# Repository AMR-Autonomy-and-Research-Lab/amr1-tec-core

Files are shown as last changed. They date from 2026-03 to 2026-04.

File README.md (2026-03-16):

<div align="center">

<br/>



<br/><br/>

# AMR1-TEC-CORE

### Plataforma de Robótica Móvil Autónoma — Hardware + Firmware + CAD

<br/>







<br/>

> Plataforma completa de robótica móvil autónoma — incluye diseño CAD del chasis, PCB personalizada con bus CAN, control de actuadores en lazo cerrado y telemetría en tiempo real. Desarrollada con estándares de producción para investigación en el Tec de Monterrey.

<br/>

</div>

---

## Visor 3D del Robot AMR1

<div align="center">

<br/>

**Chasis completo del AMR1 — haz clic para inspeccionar el ensamble 3D en tu navegador.**

<br/>

<a href="https://htmlpreview.github.io/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">
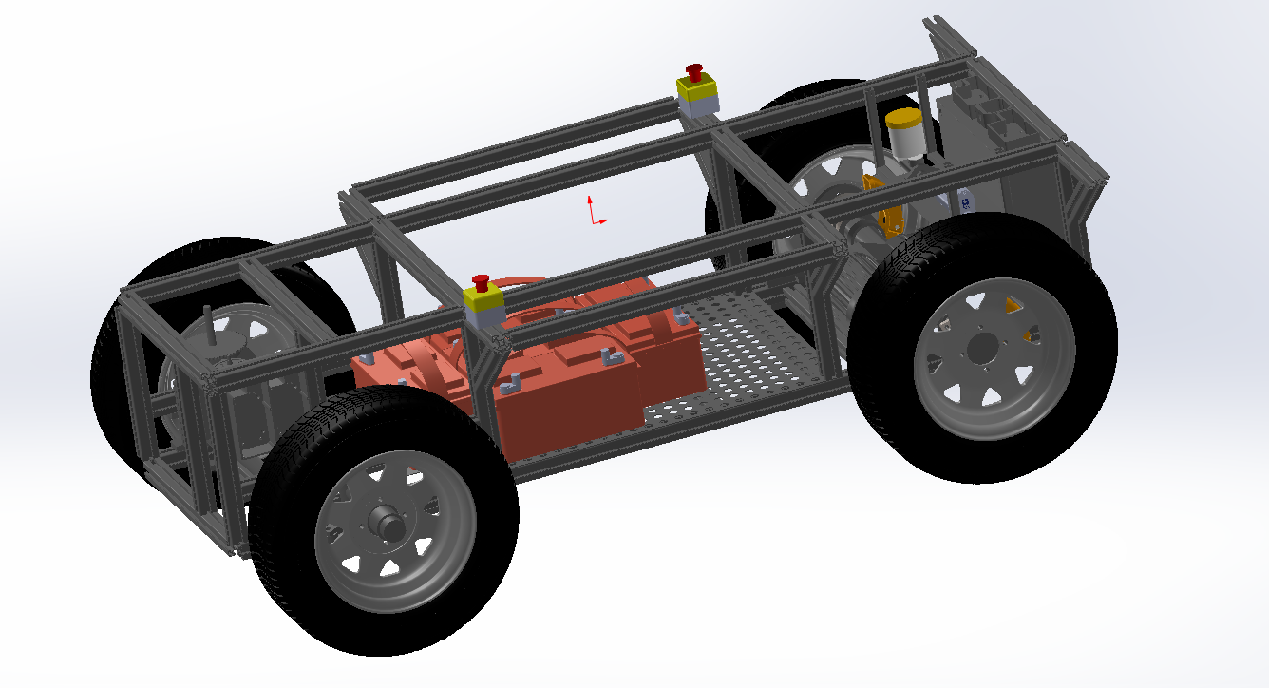
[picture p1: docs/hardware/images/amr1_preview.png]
Abrir Visor 3D del Robot AMR1
  
</a>

<br/><br/>

<a href="https://htmlpreview.github.io/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">
  
</a>

<br/><br/>

</div>

---

## Visor 3D de la PCB + Mapa iBOM

<div align="center">

<br/>

**PCB personalizada AMR1-TEC-CORE — haz clic para abrirla en el visor 3D interactivo.**

<br/>

<a href="https://htmlpreview.github.io/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">
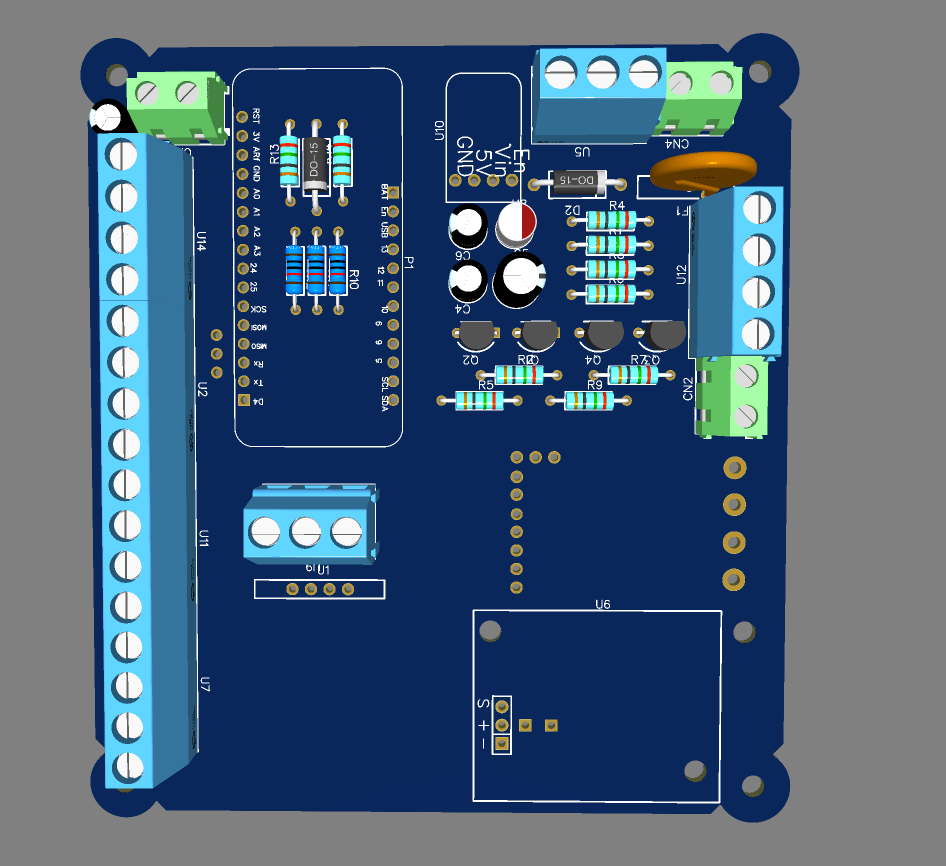
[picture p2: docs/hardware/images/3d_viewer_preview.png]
Abrir Visor 3D Interactivo de la PCB
  
</a>

<br/><br/>

<a href="https://htmlpreview.github.io/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">
  
</a>
&nbsp;&nbsp;
<a href="https://htmlpreview.github.io/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">
  
</a>

<br/><br/>

| Herramienta | Tecnología | Descripción |
|:---:|:---:|:---|
| **Visor 3D Robot** | WebGL · Three.js | Inspección del chasis completo en 3D |
| **Visor 3D PCB** | WebGL · Three.js | Inspección visual y verificación geométrica |
| **Mapa iBOM** | HTML interactivo | Guía de soldadura, localización de componentes |

<br/>

</div>

---

## Especificaciones Técnicas

<div align="center">

### Robot AMR1 — Sistema Completo

| Parámetro | Valor |
|---|---|
| Chasis | Diseño propio en SolidWorks |
| Tracción | 4 ruedas — Motor eléctrico MY1016Z3 |
| Frenado | Sistema hidráulico de pinza (Pololu Glideforce LD) |
| Alimentación | Batería 12 V |
| Control | Feather RP2040 CAN via Bus CAN |
| Comunicación | CAN 500 kbps |

### PCB — Control Central y Comunicaciones

| Parámetro | Valor |
|---|---|
| Microcontrolador | Adafruit Feather RP2040 CAN |
| Controlador CAN | MCP2515 (SPI) |
| Velocidad Bus CAN | 500 kbps |
| Entrada Serie | UART 115200 baud |
| Factor de Forma | Compatible Feather |

### PCB — Control de Actuador Lineal (Lazo Cerrado)

| Parámetro | Valor |
|---|---|
| Actuador | Pololu Glideforce High-Speed LD |
| Carga nominal | 12 kgf |
| Carrera | 6 pulgadas |
| Alimentación | 12 V |
| Control | PWM + Dirección + retroalimentación FLT |
| Sensor de posición | Potenciómetro (ADC) |

### PCB — Display de Telemetría a Bordo

| Parámetro | Valor |
|---|---|
| Display | SSD1306 OLED 128×64 |
| Interfaz | I²C |
| Datos mostrados | Estado CAN · Ciclo PWM · Corriente · Diagnóstico FLT |

</div>

---

## Arquitectura del Sistema

```
┌─────────────────────────────────────────────────────────┐
│                     AMR1 — Sistema Completo              │
│                                                          │
│  PC / ROS   ──UART 115200──►  Feather RP2040 CAN (TX)   │
│                                      │                   │
│                               Bus CAN 500 kbps           │
│                                      │                   │
│                         ┌────────────▼──────────────┐    │
│                         │  Feather RP2040 CAN (RX)  │    │
│                         │  + SSD1306 OLED 128×64    │    │
│                         └────────────┬──────────────┘    │
│                                      │                   │
│              ┌───────────────────────┼──────────────┐    │
│              │                       │              │    │
│         PWM+DIR                  PWM+DIR        I²C │    │
│              │                       │              │    │
│      ┌───────▼──────┐       ┌────────▼──────┐  ┌───▼──┐ │
│      │  Motor Drive  │       │ Actuador Lin. │  │ OLED │ │
│      │  MY1016Z3     │       │ Pololu 12kgf  │  │ 128x │ │
│      │  Tracción     │       │ ◄── ADC pos.  │  │  64  │ │
│      └───────────────┘       └───────────────┘  └──────┘ │
└─────────────────────────────────────────────────────────┘
```

---

## Estructura del Repositorio

```
amr1-tec-core/
├── AMR1_CAD/                    # Diseño CAD completo del robot
│   ├── amr1.SLDASM              # Ensamble principal SolidWorks
│   ├── amr1.STEP                # Export universal STEP
│   ├── amr1.glb                 # Modelo 3D optimizado para visor WebGL
│   └── *.SLDPRT                 # Piezas individuales del chasis
├── PCB_Design/
│   ├── PCB_AMR_Gerber/          # Gerbers validados — listos para fabricación
│   └── PCB_AMR_Gerber.zip       # ZIP directo para JLCPCB o PCBWay
├── 3D_Models/
│   └── PCB_3D/
│       └── PCB_Final.glb        # Modelo 3D de la PCB para el visor WebGL
├── feather_can_tx/              # Firmware: Transmisor Serial → CAN
├── feather_can_rx/              # Firmware: Receptor CAN + control de actuadores
├── Diseño_CAJA/                 # Modelos STL de la carcasa protectora
└── docs/hardware/
    ├── ibom_final.html          # Mapa interactivo de componentes (iBOM)
    ├── 3d_viewer/
    │   └── index.html           # Visor WebGL 3D de la PCB (auto-contenido)
    └── amr1_viewer/
        └── index.html           # Visor WebGL 3D del Robot AMR1 (auto-contenido)
```

---

## Fabricación de la PCB

Los archivos Gerber están validados y listos para ordenar directamente.

1. Ve a `PCB_Design/PCB_AMR_Gerber/` o descarga `PCB_AMR_Gerber.zip`
2. Sube el ZIP a [JLCPCB](https://jlcpcb.com) o [PCBWay](https://www.pcbway.com)
3. El diseño usa tolerancias comerciales estándar, taladros PTH/NPTH y máscara de soldadura doble capa — sin parámetros especiales

---

<div align="center">
<br/>

Desarrollado por el **AMR Autonomy and Research Lab** · Tecnológico de Monterrey



<br/>
</div>

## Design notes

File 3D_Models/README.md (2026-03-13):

# 🎨 Modelos 3D — AMR TEC Core

Modelos STL para impresión 3D y ensamblaje del robot AMR.

## Contenido

| Ubicación | Archivo | Descripción |
|---|---|---|
| `Diseño_CAJA/` | `CajaNuevaAMRF2.STL` | Enclosure/carcasa principal del sistema (v2, casi final) |

Este directorio está reservado para modelos 3D adicionales del proyecto.

## Especificaciones de impresión recomendadas

- **Material:** PLA o PETG
- **Espesor de capa:** 0.2 mm
- **Relleno:** 20–30%
- **Soporte:** Según geometría

## Visualización

Los archivos `.STL` pueden visualizarse con:
- [ViewSTL](https://www.viewstl.com/) (online)
- Blender
- Fusion 360
- PrusaSlicer / Cura

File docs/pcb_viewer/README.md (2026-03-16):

# PCB 3D Viewer (tscircuit)

Intento de integración con [@tscircuit/3d-viewer](https://github.com/tscircuit/3d-viewer).  
**Estado:** No compila por dependencias faltantes en el ecosistema tscircuit (miniflex, schematic-trace-solver, etc.).

## Alternativa

Usa **[pcb_viewer.html](../pcb_viewer.html)** para enlaces al playground de tscircuit y recursos PCB.

## Cómo probar tscircuit en el futuro

Si tscircuit corrige sus dependencias:

```bash
npm install
npm run dev
```

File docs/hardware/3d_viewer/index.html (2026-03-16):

## AMR1-TEC-CORE — Visor 3D de PCB

Clic + arrastrar: rotar · Rueda: zoom · Clic derecho: desplazar

Iniciando Three.js...

Error desconocido.

Abre la consola del navegador (F12 → Console) para ver el error completo.
↻ Reintentar

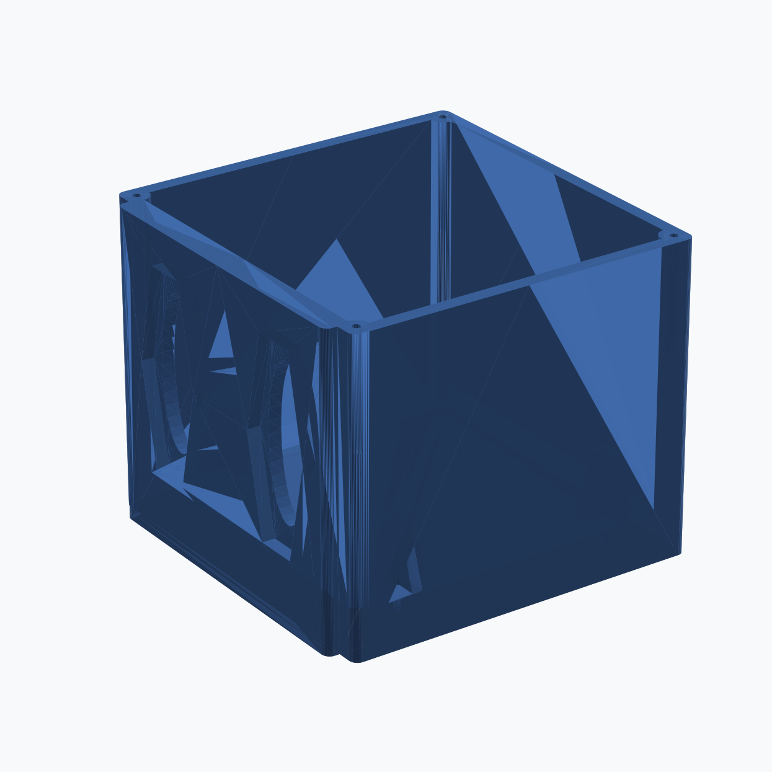
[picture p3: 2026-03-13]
docs/caja_preview.png

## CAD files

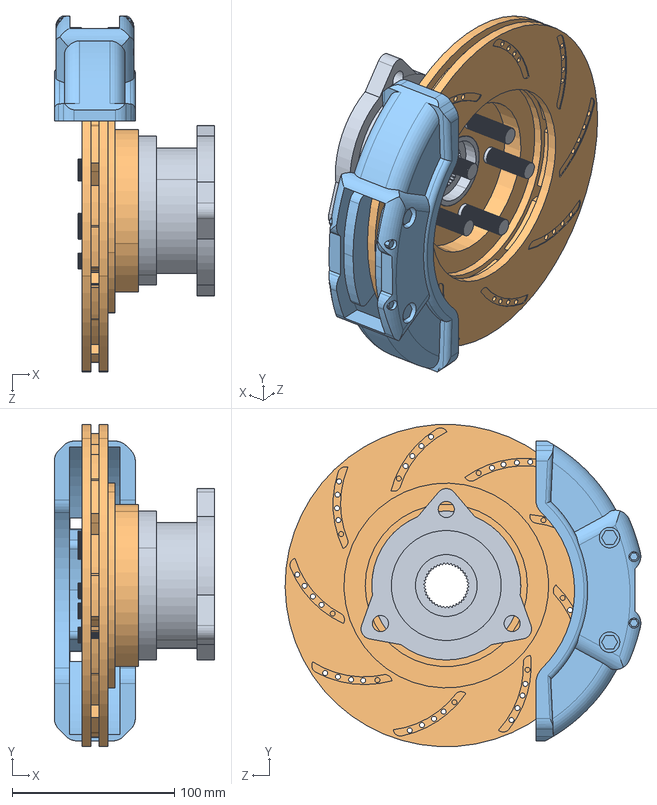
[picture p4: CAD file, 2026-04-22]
AMR1_CAD/assembly 2.SLDASM
98.9 x 198.5 x 219.3 mm
Hub 1
disc 1
calliper 1

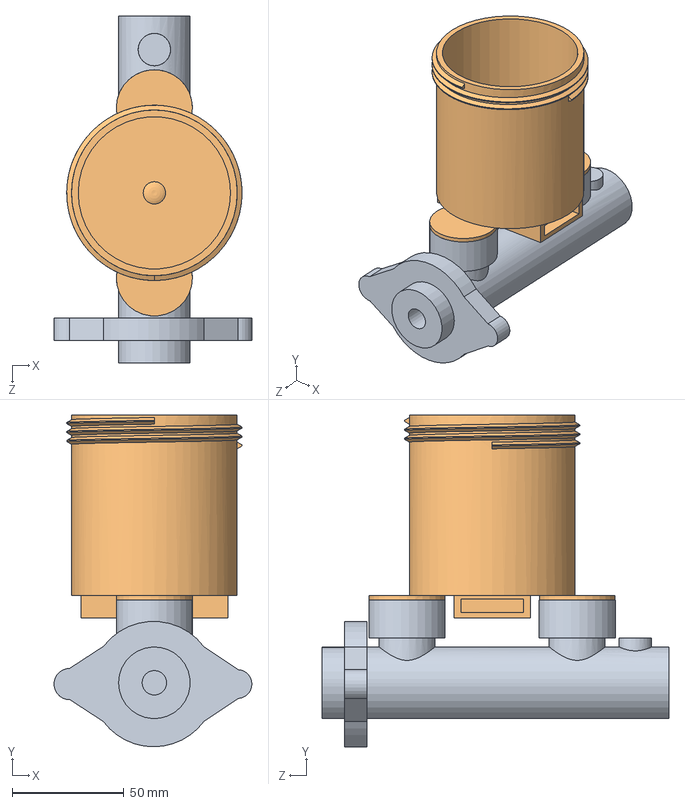
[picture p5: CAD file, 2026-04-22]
AMR1_CAD/Brake Fluid container with cylinder.SLDASM
88.4 x 148.1 x 155.0 mm
Zylinder vom Behälter
Bremsflüssigkeitsbehälter

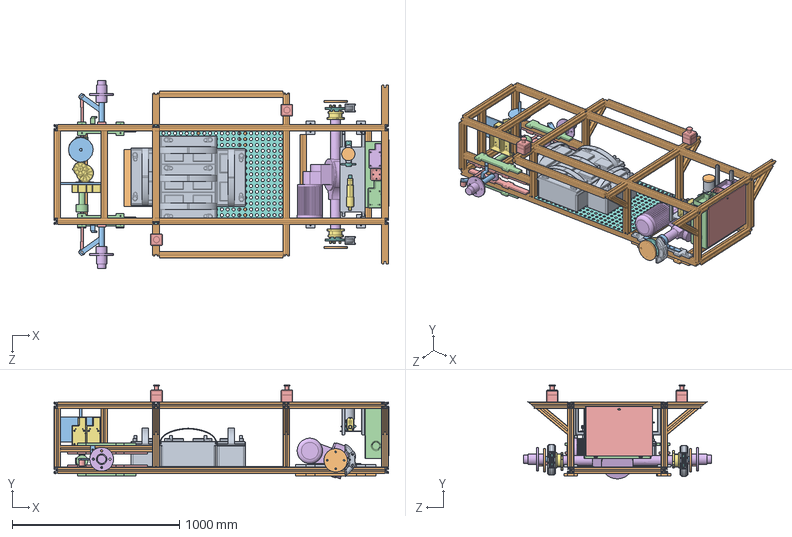
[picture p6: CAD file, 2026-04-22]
AMR1_CAD/amr1.SLDASM
2003.8 x 560.6 x 1122.0 mm
Rahmen Auto
control-module-plate
wheel-mounting1 x 4
wheel-mounting2 x 4
axle-joint x 2
cylinder-plate
Motor MY1016Z3
battery-plate
Battery x 5
battery-plate2
axle-front x 2
Blechkasten
Tür
wheel-connection x 2
aluminum-frame_2in with pot.step
extension-tube_2in frame.step
wheel-mounting1-back x 2
wheel-mounting2-back x 2
wheel-mounting3-back x 2
steering
steering-rod x 2
Powertrain
Hub 1 x 2
disc 1 x 2
calliper 1 x 2
distance-washer x 2
pinion
CarcasaInterprete
RelesFrenos
CarcasaFreno
CarcasaTrenMotriz x 2
Zylinder vom Behälter
Bremsflüssigkeitsbehälter
Behälter Deckel
steering-sensor-l
steering-sensor-r
emergency-buton x 2

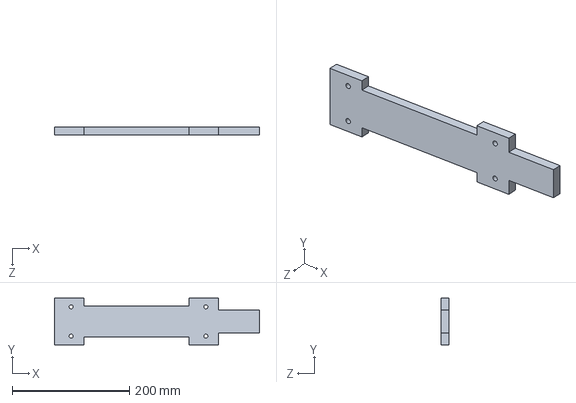
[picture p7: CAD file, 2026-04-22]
AMR1_CAD/wheel-mounting1.SLDPRT
350.0 x 80.0 x 13.0 mm

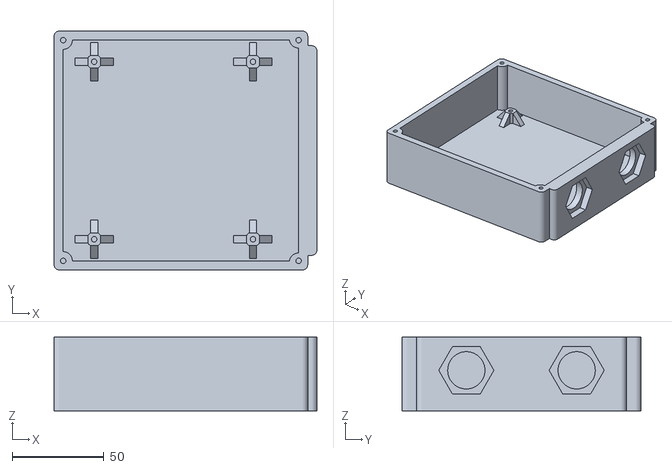
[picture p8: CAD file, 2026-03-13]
Diseño_CAJA/CajaNuevaAMRF2.STL
143.0 x 130.0 x 40.0

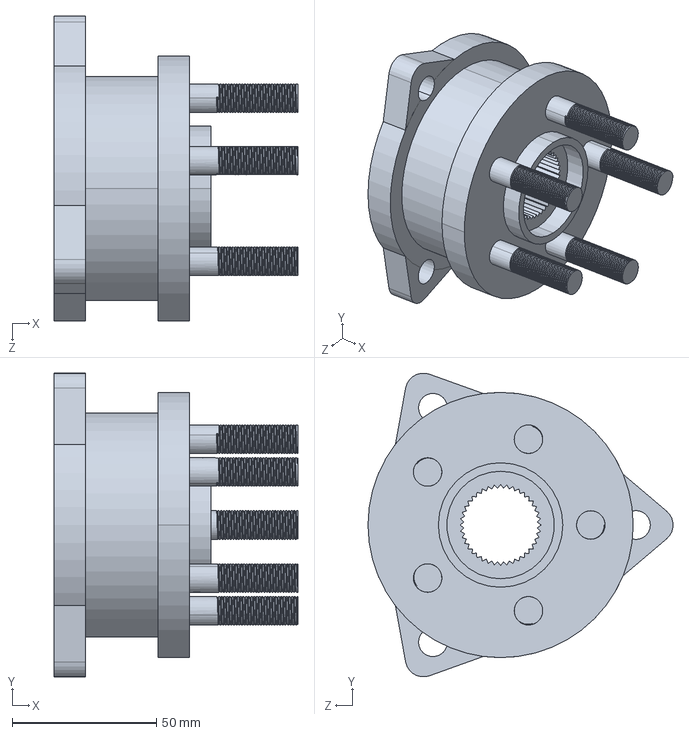
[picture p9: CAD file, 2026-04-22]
AMR1_CAD/Hub 1.SLDPRT
84.4 x 105.1 x 105.7 mm

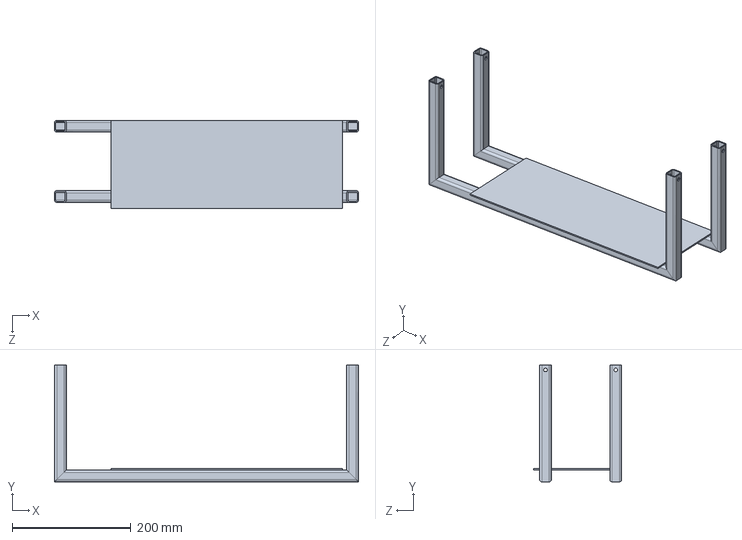
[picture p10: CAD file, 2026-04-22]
AMR1_CAD/cylinder-plate.SLDPRT
512.5 x 197.0 x 149.0 mm

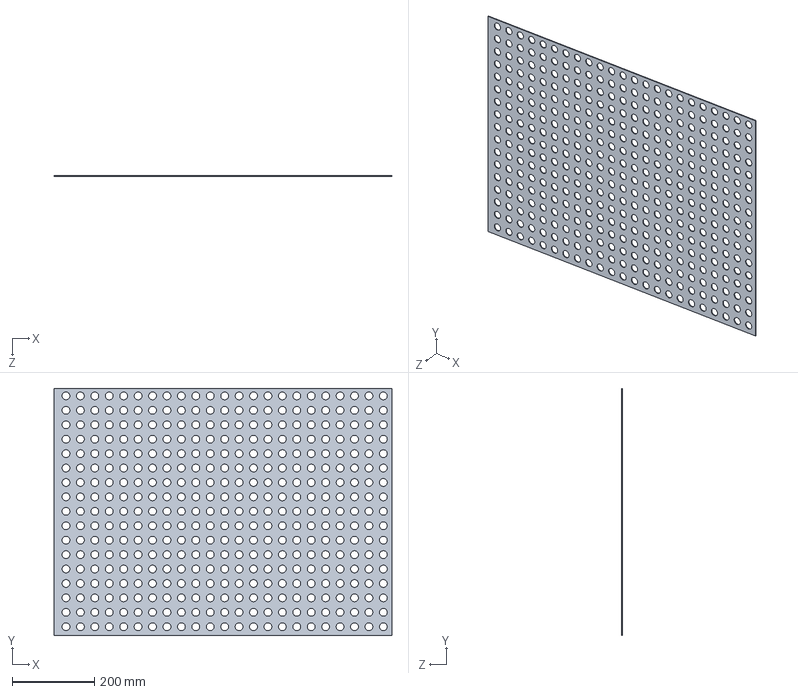
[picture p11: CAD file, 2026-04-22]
AMR1_CAD/battery-plate.SLDPRT
820.0 x 600.0 x 2.00 mm

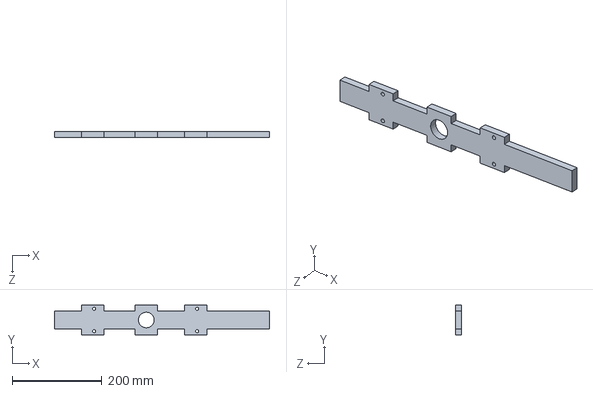
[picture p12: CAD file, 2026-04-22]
AMR1_CAD/wheel-mounting2.SLDPRT
480.0 x 66.4 x 13.0 mm

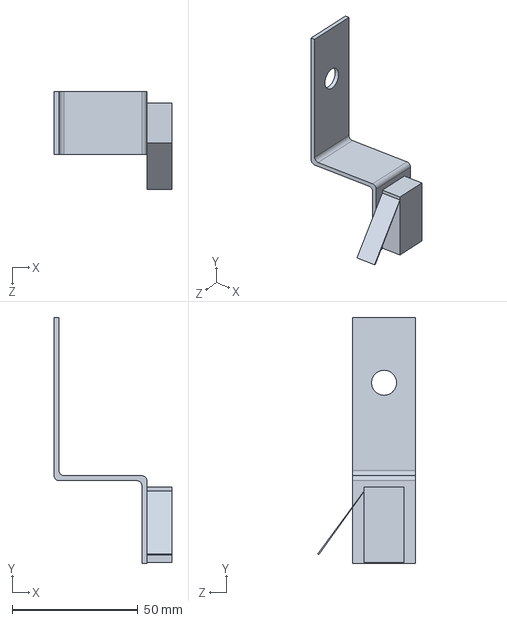
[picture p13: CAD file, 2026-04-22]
AMR1_CAD/steering-sensor-r.SLDPRT
47.0 x 98.0 x 39.0 mm

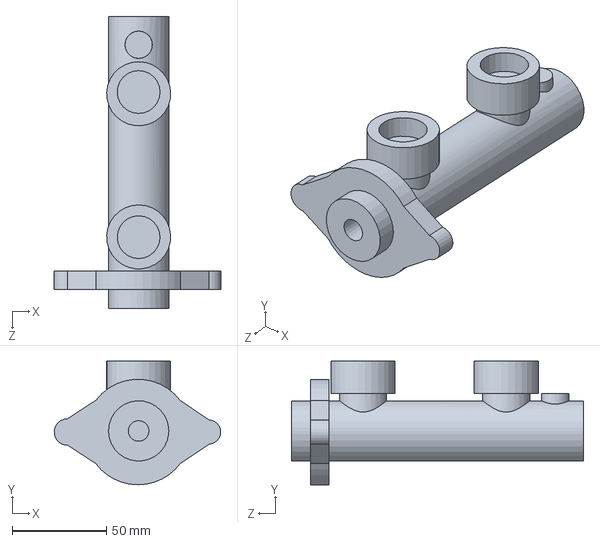
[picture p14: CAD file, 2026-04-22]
AMR1_CAD/Zylinder vom Behälter.SLDPRT
88.4 x 65.6 x 155.0 mm

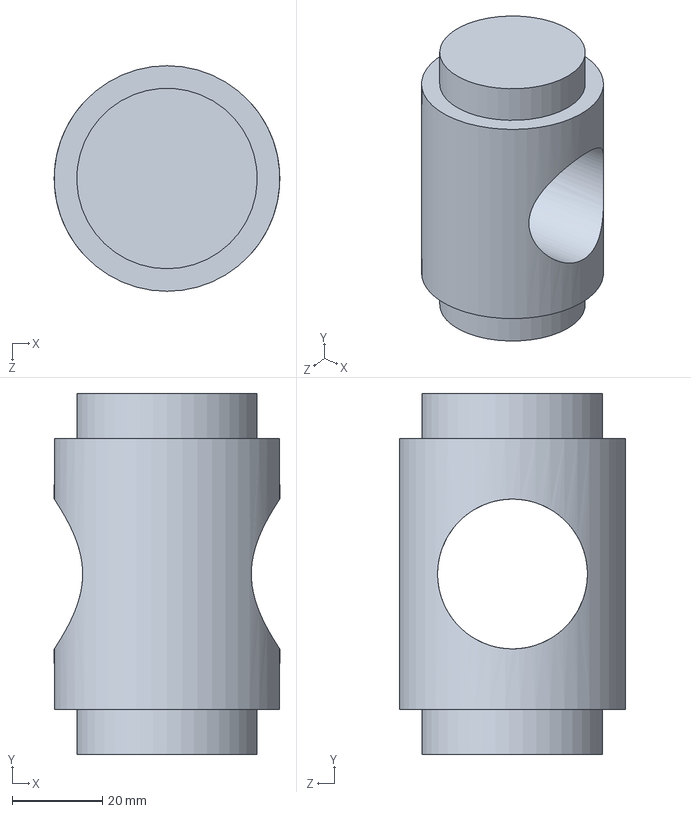
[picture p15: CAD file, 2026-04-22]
AMR1_CAD/axle-joint.SLDPRT
50.0 x 80.0 x 50.0 mm

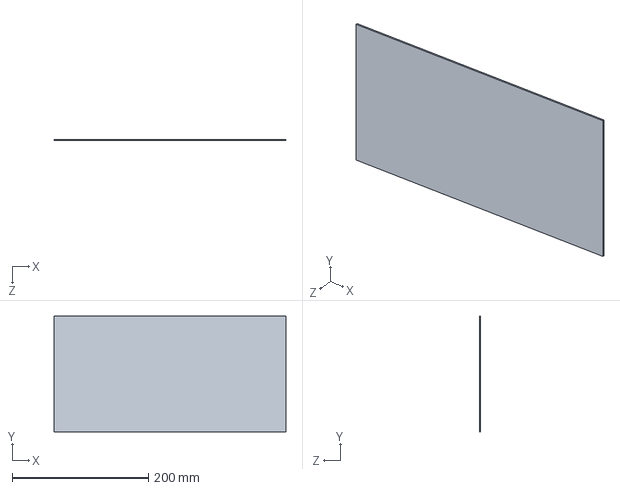
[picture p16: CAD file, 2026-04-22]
AMR1_CAD/battery-plate2.SLDPRT
340.0 x 170.0 x 2.00 mm

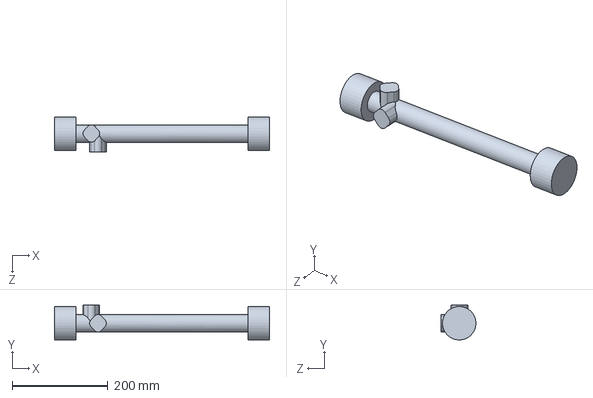
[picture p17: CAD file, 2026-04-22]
AMR1_CAD/steering.SLDPRT
450.0 x 72.9 x 73.0 mm

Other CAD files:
docs/caja_ascii.stl
AMR1_CAD/Glideforce-LD-LACT2P.step
AMR1_CAD/control-module-plate.SLDPRT
AMR1_CAD/Blechkasten.SLDPRT
AMR1_CAD/Battery.SLDPRT
AMR1_CAD/Behälter Deckel.SLDPRT
AMR1_CAD/Bremsflüssigkeitsbehälter.SLDPRT
AMR1_CAD/CarcasaFreno.SLDPRT
AMR1_CAD/CarcasaInterprete.SLDPRT
AMR1_CAD/CarcasaTrenMotriz.SLDPRT
AMR1_CAD/Motor MY1016Z3.SLDPRT
AMR1_CAD/Powertrain.SLDPRT
AMR1_CAD/Rahmen Auto.SLDPRT
AMR1_CAD/RelesFrenos.SLDPRT
AMR1_CAD/Tür.SLDPRT
AMR1_CAD/axle-front.SLDPRT
AMR1_CAD/calliper 1.SLDPRT
AMR1_CAD/disc 1.SLDPRT
AMR1_CAD/distance-washer.SLDPRT
AMR1_CAD/emergency-buton.SLDPRT
AMR1_CAD/nut.SLDPRT
AMR1_CAD/pinion.SLDPRT
AMR1_CAD/steering-rod.SLDPRT
AMR1_CAD/steering-sensor-l.SLDPRT
AMR1_CAD/wheel-connection.SLDPRT
AMR1_CAD/wheel-mounting1-back.SLDPRT
AMR1_CAD/wheel-mounting2-back.SLDPRT
AMR1_CAD/wheel-mounting3-back.SLDPRT
AMR1_CAD/wheel.SLDPRT

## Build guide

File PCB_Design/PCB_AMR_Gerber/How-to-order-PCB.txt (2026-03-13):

How to Order PCB

Please refer to:
https://docs.easyeda.com/en/PCB/Order-PCB

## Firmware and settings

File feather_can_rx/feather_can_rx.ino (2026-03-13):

/**
 * ========================================================
 *  Feather CAN RX — Receptor por CAN (Serial → TX → CAN → RX)
 * ========================================================
 *
 *  Flujo: en la otra placa (TX) escribes comandos por Serial (B/D/M);
 *  el TX los envía por CAN; esta placa (RX) los recibe y aplica al motor.
 *
 *  Actuador: Pololu Glideforce High-Speed LD, 12kgf, 6" stroke, 12V
 *  (control por PWM + dirección; driver con FLT y sensor de corriente)
 *
 *  Pinout Feather RP2040 CAN (POLOLU):
 *    PWM  = D6   (velocidad)
 *    DIR  = D9   (dirección)
 *    FLT  = D5   (falla, activo bajo)
 *    CS   = A3   (sensor de corriente)
 *  Pistón (feedback): Pot = A0
 *
 *  Sistema de frenos (protocolo compa): setpoint por 0x200, feedback 0x201, emergencia 0x210.
 *  Lazo cerrado con pot A0 (filtro media móvil, calibración RAW_MIN/RAW_MAX).
 *
 *  IDs recibidos:
 *    0x200 Setpoint   (1 byte) = posición objetivo 5–99; responde 0x201 con posición actual
 *    0x210 Emergencia (1 byte) = 1 → ir a 0%, 0 → modo normal
 *    0x42  Freno      (1 byte) = setpoint (compatibilidad), responde 0x201
 *    0x53  Dirección  (1 byte)
 *    0x54  Motor      (5 bytes)
 *    0x20  Comando    (2 bytes — legacy)
 *    0x30  Vista OLED (1 byte: 1=CAN addr, 2=Pololu) — Serial "1"/"2" o TX
 *  ID enviado: 0x201 = posición actual freno (1 byte, 0–100)
 *
 *  Baudrate : 500 kbps
 *  Librería : Adafruit_MCP2515 (API: parsePacket/read)
 *  Display  : SSD1306 128×64 I2C
 */

// ─── Librerías ──────────────────────────────────────────
#include <Adafruit_MCP2515.h>
#include <Wire.h>
#include <Adafruit_GFX.h>
#include <Adafruit_SSD1306.h>

// ─── Pines según placa ─────────────────────────────────
#ifdef ARDUINO_ADAFRUIT_FEATHER_RP2040_CAN
  #define CS_PIN   PIN_CAN_CS        // Pin 19 en Feather RP2040 CAN
  #define LED_PIN  13
#else
  #define CS_PIN   19               // Feather RP2040 CAN: usa 19 si no está la placa en IDE
  #define LED_PIN  13
#endif

// ─── Configuración CAN ─────────────────────────────────
#define CAN_BAUDRATE    500000        // 500 kbps

#define CAN_ID_SETPOINT 0x200         // Setpoint posición actuador (como compa)
#define CAN_ID_FEEDBACK 0x201        // Respuesta posición actual (1 byte)
#define CAN_ID_EMERGENCIA 0x210      // Emergencia: 1=ir a 0%, 0=normal
#define CAN_ID_FRENO    0x42         // Compatibilidad: mismo setpoint que 0x200
#define CAN_ID_DIR      0x53
#define CAN_ID_MOT      0x54
#define CAN_ID_CMD      0x20          // legacy: 2 bytes [PWM, DIR]
#define CAN_ID_VIEW     0x30          // Modo vista: 1=CAN addr, 2=Pololu
#define MY_CAN_ADDR     0x01          // Dirección CAN de esta placa (cámbiala si tienes varias)

// ─── Frenos: calibración y control (YRA/Machinime/Peter) ────
#define RAW_MIN        820            // Pot A0: mínimo raw (heurístico)
#define RAW_MAX        890            // Máximo raw; más podría dañar el freno — cuidado
#define BRAKE_TOLERANCIA 1            // ±1% zona muerta
#define BRAKE_PWM_MIN  140            // PWM mínimo al mover (compa 140)
#define BRAKE_PWM_MAX  255            // PWM máximo
// Polaridad: 0 = estándar. Si al subir setpoint el actuador baja, pon 1
#define INVERTIR_DIR_ACTUADOR 0

#define DEBUG_CAN       1             // 1 = imprimir tramas por Serial

// ─── OLED 0.96" SSD1306 I2C ────────────────────────────
#define SCREEN_WIDTH    128
#define SCREEN_HEIGHT   64
#define OLED_RESET      -1
#define SCREEN_ADDRESS  0x3C
Adafruit_SSD1306 display(SCREEN_WIDTH, SCREEN_HEIGHT, &Wire, OLED_RESET);
bool oledOk = false;

// ─── Objeto CAN ────────────────────────────────────────
Adafruit_MCP2515 mcp(CS_PIN);
bool canOk = false;

// ─── Pines Pololu / actuador Glideforce (Feather RP2040 CAN) ────
const uint8_t PIN_PWM = 6;          // D6  — PWM velocidad
const uint8_t PIN_DIR = 9;          // D9  — Dirección (extender/retraer)
const uint8_t PIN_FLT = 5;          // D5  — Fault (activo bajo)
const uint8_t PIN_CS  = A3;         // A3  — Sensor de corriente
const uint8_t PIN_POT = A0;         // A0  — Pistón: potenciómetro feedback

// ─── Constantes sensor de corriente ────────────────────
const float ADC_REF        = 3.3f;
const int   ADC_RES        = 1023;
const float CS_SENSITIVITY = 0.020f;   // V/A
const float CS_OFFSET      = 0.050f;   // V offset

// ─── Variables de recepción CAN ─────────────────────────
uint8_t lastFreno    = 0;             // 0x42, byte 0
uint8_t lastDir      = 0;             // 0x53, byte 0
uint8_t lastMotVel   = 0;             // 0x54, byte 0
uint8_t lastMotEn    = 0;             // 0x54, byte 1
uint8_t lastMotRev   = 0;             // 0x54, byte 2
uint8_t lastMotLo    = 0;             // 0x54, byte 3
uint8_t lastMotHi    = 0;             // 0x54, byte 4
unsigned long lastRxMs  = 0;
unsigned long rxCount   = 0;

// ─── Variables de salida motor / freno ───────────────────
int   rxPWM     = 0;
int   rxDIR     = 0;
float currentA  = 0.0f;
bool  fault     = false;
int   potRaw    = 0;                // Pistón: lectura pot A0 (raw)
int   setValueBrake = 0;            // Setpoint posición freno (0–100) desde CAN 0x200/0x42
int   posBrake  = 0;                // Posición actual mapeada 0–100
bool  modoEmergencia = false;       // 0x210: true → objetivo 0%

// ─── Filtro media móvil pot (como compa, N=5) ────
#define POT_FILTER_N    5
int   bufferLecturas[POT_FILTER_N];
long  sumaLecturasPot  = 0;
int   indicePot        = 0;
bool  bufferPotLleno   = false;

// ─── Modo vista OLED: 1=solo dir CAN, 2=Pololu ─
uint8_t displayMode = 1;             // Serial "1"/"2" o CAN 0x30

// ─── Temporización OLED ─────────────────────────────────
#define OLED_INTERVAL_MS  250         // refrescar OLED cada 250 ms
unsigned long lastOledMs = 0;

// ─── Serial: buffer para comando vista ──────────────────
#define SERIAL_VIEW_BUF  8
char    serialViewBuf[SERIAL_VIEW_BUF];
uint8_t serialViewIdx = 0;

// ─── Prototipos ─────────────────────────────────────────
void initOLED();
void initCAN();
void initMotorPins();
void pollCAN();
void processPacket(long id, uint8_t* buf, uint8_t len);
void readCurrentSensor();
void enviarFeedbackCAN();            // Envía posBrake por CAN 0x201
void brakeControl();                // Lazo cerrado freno: SetValue vs Pot, actualiza rxPWM/rxDIR
void driveMotor();
void processSerialView();
void refreshDisplay();               // Refresco cada 250 ms
void drawCurrentVista();             // Dibuja la vista actual YA (sin esperar intervalo)
void printMenuInicio();              // Mini interfaz al cargar
void updateOLED_vista1_CAN();       // 1: solo dirección CAN
void updateOLED_vista2_Pololu();    // 2: datos Pololu
void blinkLed();

// ═════════════════════════════════════════════════════════
//  SETUP
// ═════════════════════════════════════════════════════════
void setup() {
  Serial.begin(115200);
  delay(2500);

  pinMode(LED_PIN, OUTPUT);
  digitalWrite(LED_PIN, LOW);

  Serial.println(F("========================================"));
  Serial.println(F("  Feather CAN RX — Receptor"));
  Serial.println(F("========================================"));
  Serial.print(F("  CS Pin    : ")); Serial.println(CS_PIN);
  Serial.print(F("  Baudrate  : ")); Serial.print(CAN_BAUDRATE / 1000);
  Serial.println(F(" kbps"));
  Serial.println(F("========================================"));
  printMenuInicio();

  initMotorPins();
  initOLED();
  initCAN();

  // Inicializar filtro media móvil del pot y setpoint = posición actual (no mover al arranque)
  for (int i = 0; i < POT_FILTER_N; i++) {
    bufferLecturas[i] = analogRead(PIN_POT);
    sumaLecturasPot += bufferLecturas[i];
  }
  bufferPotLleno = true;
  readCurrentSensor();
  setValueBrake = posBrake;
  enviarFeedbackCAN();
}

// ═════════════════════════════════════════════════════════
//  LOOP — Ligero: solo funciones (lógica fuera del loop)
// ═════════════════════════════════════════════════════════
void loop() {
  pollCAN();
  readCurrentSensor();
  brakeControl();                   // Frenos: setpoint 0x42 vs pot → rxPWM, rxDIR
  driveMotor();
  processSerialView();
  refreshDisplay();
}

// ═════════════════════════════════════════════════════════
//  Inicialización pines motor Pololu
// ═════════════════════════════════════════════════════════
void initMotorPins() {
  pinMode(PIN_PWM, OUTPUT);
  pinMode(PIN_DIR, OUTPUT);
  pinMode(PIN_FLT, INPUT_PULLUP);
  pinMode(PIN_CS,  INPUT);
  pinMode(PIN_POT, INPUT);           // Pistón: pot feedback (A0)

  analogWrite(PIN_PWM, 0);
  digitalWrite(PIN_DIR, LOW);
}

// ═════════════════════════════════════════════════════════
//  Inicialización OLED
// ═════════════════════════════════════════════════════════
void initOLED() {
  Serial.print(F("OLED init... "));
  oledOk = display.begin(SSD1306_SWITCHCAPVCC, SCREEN_ADDRESS);
  if (!oledOk) {
    Serial.println(F("no encontrada"));
    return;
  }
  Serial.println(F("OK"));

  display.clearDisplay();
  display.drawRect(0, 0, SCREEN_WIDTH, SCREEN_HEIGHT, SSD1306_WHITE);
  display.setTextSize(1);
  display.setTextColor(SSD1306_WHITE);
  display.setCursor(4, 4);
  display.println(F("AMR  CAN RX"));
  display.drawFastHLine(0, 14, SCREEN_WIDTH, SSD1306_WHITE);
  display.setCursor(4, 18);
  display.println(F("500 kbps  Listo."));
  display.setCursor(4, 30);
  display.println(F("1=CAN  2=Pololu"));
  display.display();
}

// ═════════════════════════════════════════════════════════
//  Inicialización CAN
// ═════════════════════════════════════════════════════════
void initCAN() {
  if (!mcp.begin(CAN_BAUDRATE)) {
    Serial.println(F("[ERROR] No se pudo inicializar MCP2515"));
    canOk = false;
    while (1) {                       // Parpadeo rápido = error
      digitalWrite(LED_PIN, HIGH); delay(100);
      digitalWrite(LED_PIN, LOW);  delay(100);
    }
  }
  canOk = true;
  Serial.println(F("[OK] MCP2515 inicializado correctamente"));
}

// ═════════════════════════════════════════════════════════
//  Leer tramas CAN (poll)
// ═════════════════════════════════════════════════════════
void pollCAN() {
  if (!canOk) return;

  int packetSize = mcp.parsePacket();
  if (packetSize <= 0) return;        // nada disponible

  long id      = mcp.packetId();
  uint8_t len  = (uint8_t)packetSize;
  uint8_t buf[8] = {0};

  for (uint8_t i = 0; i < len && i < 8; i++) {
    if (mcp.available()) buf[i] = (uint8_t)mcp.read();
  }

  lastRxMs = millis();
  rxCount++;
  blinkLed();

  // Debug por Serial
  if (DEBUG_CAN) {
    Serial.print(F("[RX] 0x")); Serial.print((uint16_t)id, HEX);
    Serial.print(F(" len=")); Serial.print(len);
    Serial.print(F(" data:"));
    for (uint8_t i = 0; i < len && i < 8; i++) {
      Serial.print(' '); Serial.print(buf[i]);
    }
    Serial.println();
  }

  processPacket(id, buf, len);
}

// ═════════════════════════════════════════════════════════
//  Procesar paquete según ID
// ═════════════════════════════════════════════════════════
void processPacket(long id, uint8_t* buf, uint8_t len) {

  // 0x200 — Setpoint posición (como compa): 5–99, responde 0x201
  if (id == CAN_ID_SETPOINT && len >= 1 && !modoEmergencia) {
    lastFreno = buf[0];
    setValueBrake = (int)buf[0];
    setValueBrake = constrain(setValueBrake, 5, 99);
    enviarFeedbackCAN();
    if (DEBUG_CAN) {
      Serial.print(F("  -> Setpoint 0x200 Set=")); Serial.print(setValueBrake);
      Serial.print(F(" Pos=")); Serial.println(posBrake);
    }
  }

  // 0x210 — Emergencia: 1 = ir a 0%, 0 = modo normal
  if (id == CAN_ID_EMERGENCIA && len >= 1) {
    if (buf[0] == 1) {
      modoEmergencia = true;
      setValueBrake = 0;
    } else if (buf[0] == 0) {
      modoEmergencia = false;
    }
    if (DEBUG_CAN) Serial.println(modoEmergencia ? F("  -> Emergencia ON (0%)") : F("  -> Emergencia OFF"));
  }

  // 0x42 — Freno (compatibilidad): mismo setpoint, responde 0x201
  if (id == CAN_ID_FRENO && len >= 1) {
    lastFreno = buf[0];
    setValueBrake = constrain((int)buf[0], 0, 100);
    enviarFeedbackCAN();
    if (DEBUG_CAN) {
      Serial.print(F("  -> Freno 0x42 Set=")); Serial.print(setValueBrake);
      Serial.print(F(" Pos=")); Serial.println(posBrake);
    }
  }

  // 0x53 — Dirección (1 byte, ≥50 = B, <50 = A)
  if (id == CAN_ID_DIR && len >= 1) {
    lastDir = buf[0];
    rxDIR = (buf[0] >= 50) ? 1 : 0;
    if (DEBUG_CAN) {
      Serial.print(F("  -> Dir raw=")); Serial.print(buf[0]);
      Serial.print(F(" DIR="));         Serial.println(rxDIR);
    }
  }

  // 0x54 — Motor (5 bytes: vel, en, rev, lo, hi)
  if (id == CAN_ID_MOT && len >= 2) {
    lastMotVel = buf[0];
    lastMotEn  = buf[1];
    if (len >= 3) lastMotRev = buf[2];
    if (len >= 4) lastMotLo  = buf[3];
    if (len >= 5) lastMotHi  = buf[4];
    rxPWM = (int)buf[0];
    if (buf[1] == 0) rxPWM = 0;       // enable=0 → parar
    if (len >= 3) rxDIR = (buf[2] != 0) ? 1 : 0;  // rev → dirección actuador
    if (DEBUG_CAN) {
      Serial.print(F("  -> Mot Vel=")); Serial.print(lastMotVel);
      Serial.print(F(" En="));  Serial.print(lastMotEn);
      Serial.print(F(" Rev=")); Serial.print(lastMotRev);
      Serial.print(F(" Lo="));  Serial.print(lastMotLo);
      Serial.print(F(" Hi="));  Serial.println(lastMotHi);
    }
  }

  // 0x20 — Comando legacy (2 bytes: PWM, DIR)
  if (id == CAN_ID_CMD && len >= 2) {
    rxPWM = (int)buf[0];
    rxDIR = (int)(buf[1] & 1);
    if (DEBUG_CAN) {
      Serial.print(F("  -> Cmd PWM=")); Serial.print(rxPWM);
      Serial.print(F(" DIR="));         Serial.println(rxDIR);
    }
  }

  // 0x30 — Modo vista OLED (1=CAN, 2=Pololu)
  if (id == CAN_ID_VIEW && len >= 1) {
    if (buf[0] == 1 || buf[0] == 2) {
      displayMode = buf[0];
      drawCurrentVista();
      Serial.print(F(">>> [CAN] Vista: "));
      Serial.println(displayMode == 1 ? F("CAN (1)") : F("Pololu (2)"));
    }
  }
}

// ═════════════════════════════════════════════════════════
//  Serial: comando "1" / "2" / "3" para cambiar vista OLED (con o sin Enter)
// ═════════════════════════════════════════════════════════
static void setDisplayModeAndRedraw(uint8_t mode) {
  if (mode == 1 || mode == 2) {
    displayMode = mode;
    drawCurrentVista();
  }
}

static void printVistaCambiada(uint8_t mode) {
  Serial.print(F(">>> Vista: "));
  Serial.println(mode == 1 ? F("CAN (1)") : F("Pololu (2)"));
}

void printMenuInicio() {
  Serial.println(F("--- ¿Qué ver en la OLED? ---"));
  Serial.println(F("  1 = Dirección CAN"));
  Serial.println(F("  2 = Datos Pololu (PWM, DIR, I, FLT)"));
  Serial.println(F("  Escribe 1 o 2 (o por CAN desde TX)."));
  Serial.println(F("-----------------------------"));
}

void processSerialView() {
  while (Serial.available()) {
    char c = (char)Serial.read();
    if (c == '\n' || c == '\r') {
      if (serialViewIdx > 0) {
        serialViewBuf[serialViewIdx] = '\0';
        if (serialViewBuf[0] == '1') { setDisplayModeAndRedraw(1); printVistaCambiada(1); }
        else if (serialViewBuf[0] == '2') { setDisplayModeAndRedraw(2); printVistaCambiada(2); }
        serialViewIdx = 0;
      }
    } else if (serialViewIdx < SERIAL_VIEW_BUF - 1) {
      serialViewBuf[serialViewIdx++] = c;
      if (serialViewIdx == 1 && (serialViewBuf[0] == '1' || serialViewBuf[0] == '2')) {
        displayMode = (uint8_t)(serialViewBuf[0] - '0');
        drawCurrentVista();
        printVistaCambiada(displayMode);
        serialViewIdx = 0;
      }
    }
  }
}

// ═════════════════════════════════════════════════════════
//  Pot filtrado y porcentaje (como compa)
// ═════════════════════════════════════════════════════════
int leerPotFiltrado() {
  int nueva = analogRead(PIN_POT);
  sumaLecturasPot -= bufferLecturas[indicePot];
  bufferLecturas[indicePot] = nueva;
  sumaLecturasPot += nueva;
  indicePot++;
  if (indicePot >= POT_FILTER_N) { indicePot = 0; bufferPotLleno = true; }
  return bufferPotLleno ? (int)(sumaLecturasPot / POT_FILTER_N) : (int)(sumaLecturasPot / indicePot);
}

uint8_t lecturaToPorcentaje(int raw) {
  raw = constrain(raw, RAW_MIN, RAW_MAX);
  int pct = map(raw, RAW_MIN, RAW_MAX, 100, 0);   // compa: 100 en MIN, 0 en MAX
  return (uint8_t)constrain(pct, 0, 100);
}

void enviarFeedbackCAN() {
  if (!canOk) return;
  mcp.beginPacket(CAN_ID_FEEDBACK);
  mcp.write((uint8_t)posBrake);
  mcp.endPacket();
}

// ═════════════════════════════════════════════════════════
//  Sensor de corriente Pololu
// ═════════════════════════════════════════════════════════
void readCurrentSensor() {
  fault = (digitalRead(PIN_FLT) == LOW);

  int   adc = analogRead(PIN_CS);
  float vcs = (float)adc * ADC_REF / (float)ADC_RES;
  currentA  = (vcs - CS_OFFSET) / CS_SENSITIVITY;
  if (currentA < 0.0f) currentA = 0.0f;

  potRaw = leerPotFiltrado();
  posBrake = lecturaToPorcentaje(potRaw);
}

// ═════════════════════════════════════════════════════════
//  Control frenos — lazo cerrado (como compa: tolerancia 1, PWM 140–255)
// ═════════════════════════════════════════════════════════
void brakeControl() {
  int objetivo = modoEmergencia ? 0 : setValueBrake;
  int error = objetivo - posBrake;

  if (abs(error) <= BRAKE_TOLERANCIA) {
    rxPWM = 0;
    return;
  }
  // error > 0 → subir posición → DIR HIGH (1); error < 0 → bajar → DIR LOW (0)
  rxDIR = (error > 0) ? 1 : 0;
  rxPWM = map(abs(error), 0, 100, BRAKE_PWM_MIN, BRAKE_PWM_MAX);
  rxPWM = constrain(rxPWM, 0, 255);
}

// ═════════════════════════════════════════════════════════
//  Control motor Pololu (aplica rxPWM y rxDIR a los pines)
// ═════════════════════════════════════════════════════════
void driveMotor() {
  if (fault) {
    analogWrite(PIN_PWM, 0);
  } else {
    analogWrite(PIN_PWM, rxPWM);
#if INVERTIR_DIR_ACTUADOR
    digitalWrite(PIN_DIR, rxDIR ? LOW : HIGH);   // Polaridad invertida (Rojo/Negro)
#else
    digitalWrite(PIN_DIR, rxDIR ? HIGH : LOW);
#endif
  }
}

// ═════════════════════════════════════════════════════════
//  OLED — Dibujar vista actual YA (sin esperar intervalo)
// ═════════════════════════════════════════════════════════
void drawCurrentVista() {
  if (!oledOk) return;
  lastOledMs = millis();
  switch (displayMode) {
    case 1: updateOLED_vista1_CAN();    break;
    case 2: updateOLED_vista2_Pololu(); break;
    default: updateOLED_vista1_CAN();   break;
  }
}

// Refresco periódico (cada 250 ms)
void refreshDisplay() {
  if (!oledOk) return;
  if (millis() - lastOledMs < OLED_INTERVAL_MS) return;
  lastOledMs = millis();
  switch (displayMode) {
    case 1: updateOLED_vista1_CAN();    break;
    case 2: updateOLED_vista2_Pololu(); break;
    default: updateOLED_vista1_CAN();   break;
  }
}

// Vista 1: solo dirección CAN — Interfaz producto AMR
void updateOLED_vista1_CAN() {
  if (!oledOk) return;
  display.clearDisplay();
  display.drawRect(0, 0, SCREEN_WIDTH, SCREEN_HEIGHT, SSD1306_WHITE);
  display.setTextSize(1);
  display.setTextColor(SSD1306_WHITE);

  display.setCursor(4, 2);
  display.print(F("AMR CAN RX"));
  display.setCursor(SCREEN_WIDTH - 20, 2);
  display.print(F("V1"));
  display.drawFastHLine(0, 11, SCREEN_WIDTH, SSD1306_WHITE);

  display.setCursor(4, 16);
  display.print(F("Dir CAN"));
  display.setCursor(78, 16);
  display.print(F("0x"));
  display.println(MY_CAN_ADDR, HEX);

  display.drawFastHLine(0, 55, SCREEN_WIDTH, SSD1306_WHITE);
  display.setCursor(4, 57);
  display.print(F("RX #"));
  display.println(rxCount);

  display.display();
}

// Vista 2: datos Pololu — Interfaz producto AMR
void updateOLED_vista2_Pololu() {
  if (!oledOk) return;
  display.clearDisplay();
  display.drawRect(0, 0, SCREEN_WIDTH, SCREEN_HEIGHT, SSD1306_WHITE);
  display.setTextSize(1);
  display.setTextColor(SSD1306_WHITE);

  display.setCursor(4, 2);
  display.print(F("AMR  Pololu"));
  display.setCursor(SCREEN_WIDTH - 20, 2);
  display.print(F("V2"));
  display.drawFastHLine(0, 11, SCREEN_WIDTH, SSD1306_WHITE);

  display.setCursor(4, 14);
  display.print(F("PWM D6"));
  display.setCursor(78, 14);
  display.println(rxPWM);

  display.setCursor(4, 24);
  display.print(F("DIR D9"));
  display.setCursor(78, 24);
  display.println(rxDIR ? F("B") : F("A"));

  display.setCursor(4, 34);
  display.print(F("I (A)"));
  display.setCursor(78, 34);
  display.println(currentA, 2);

  display.setCursor(4, 44);
  display.print(F("FLT D5"));
  display.setCursor(78, 44);
  if (fault) {
    display.setTextColor(SSD1306_BLACK, SSD1306_WHITE);
    display.println(F("FAULT"));
    display.setTextColor(SSD1306_WHITE);
  } else {
    display.println(F("OK"));
  }

  display.drawFastHLine(0, 53, SCREEN_WIDTH, SSD1306_WHITE);
  display.setCursor(4, 55);
  display.print(F("Pot A0:"));
  display.print(potRaw);
  display.print(F(" RX#"));
  display.println(rxCount);

  display.display();
}

// ═════════════════════════════════════════════════════════
//  LED indicador (parpadeo al recibir)
// ═════════════════════════════════════════════════════════
void blinkLed() {
  digitalWrite(LED_PIN, HIGH);
  delay(10);
  digitalWrite(LED_PIN, LOW);
}

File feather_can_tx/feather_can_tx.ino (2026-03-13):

/**
 * ========================================================
 *  Feather CAN TX — Control manual por Serial → CAN
 * ========================================================
 *
 *  Modo: tú envías comandos por Serial; la placa los reenvía por CAN.
 *  (Como lo hacía Yoni: mensaje a la placa, de ahí por CAN a las demás.)
 *
 *  Comandos por Serial (115200 baud):
 *    B <0-100>     Setpoint actuador freno → CAN 0x200 (como compa)
 *    E 0 / E 1    Emergencia → CAN 0x210 (1=ir a 0%, 0=normal)
 *    D <0-100>     Dir     → CAN 0x53 (1 byte)
 *    M v e r l h   Motor   → CAN 0x54 (5 bytes)
 *    ? o help     Ayuda
 *
 *  Ejemplo: B 50   → posición freno 50% (0x200)
 *           200 85 o 200_85 → formato YRA/Machinime: ID + porcentaje (envía CAN 0x200 con 85)
 *           E 1    → emergencia (actuador a 0%); E 0 → normal
 *
 *  Baudrate CAN : 500 kbps
 *  Librería     : Adafruit_MCP2515
 */

// ─── Librerías ──────────────────────────────────────────
#include <Adafruit_MCP2515.h>
#include <Wire.h>
#include <Adafruit_GFX.h>
#include <Adafruit_SSD1306.h>

// ─── Pines según placa ─────────────────────────────────
#ifdef ARDUINO_ADAFRUIT_FEATHER_RP2040_CAN
  #define CS_PIN   PIN_CAN_CS        // Pin 19 en Feather RP2040 CAN
  #define LED_PIN  13
#else
  #define CS_PIN   19                // Si usas Feather RP2040 CAN con otra placa en IDE, usa 19
  #define LED_PIN  13
#endif

// ─── Configuración CAN ─────────────────────────────────
#define CAN_BAUDRATE    500000        // 500 kbps

#define CAN_ID_SETPOINT 0x200         // Setpoint posición actuador (como compa)
#define CAN_ID_EMERGENCIA 0x210      // Emergencia: 1=0%, 0=normal
#define CAN_ID_DIR      0x53
#define CAN_ID_MOT      0x54
#define CAN_ID_VIEW     0x30          // Vista OLED RX: 1=CAN addr, 2=Pololu

// ─── OLED 0.96" SSD1306 I2C ────────────────────────────
#define SCREEN_WIDTH    128
#define SCREEN_HEIGHT   64
#define OLED_RESET      -1
#define SCREEN_ADDRESS  0x3C
Adafruit_SSD1306 display(SCREEN_WIDTH, SCREEN_HEIGHT, &Wire, OLED_RESET);
bool oledOk = false;

// ─── Serial: buffer para comandos ───────────────────────
#define SERIAL_BUF_SIZE  64
char    serialBuf[SERIAL_BUF_SIZE];
uint8_t serialIdx = 0;
unsigned long txCount = 0;

// ─── Objeto CAN ────────────────────────────────────────
Adafruit_MCP2515 mcp(CS_PIN);

// ─── Valores actuales (los que envías por Serial → CAN) ─
uint8_t brakeVal  = 0;
uint8_t dirVal    = 50;
uint8_t motorVel  = 0;
uint8_t motorEn   = 1;
uint8_t motorRev  = 0;
uint8_t motorLo   = 0;
uint8_t motorHi   = 0;

// ─── Prototipos ─────────────────────────────────────────
void initOLED();
void initCAN();
void processSerial();
void parseAndSendCommand(char* line);
/** Formato "ID Porcentaje" o "ID_Porcentaje" (ej. 200 85, 200_85) → envía CAN id con 1 byte */
bool trySendIdPos(char* line);
void printHelp();
void printMenuInicio();   // Mini interfaz: qué ver y opciones
void sendBrake(uint8_t val);         // 0x200 setpoint 0–100
void sendEmergencia(uint8_t on);     // 0x210: 1=emergencia, 0=normal
void sendDir(uint8_t val);
void sendMotor(uint8_t v, uint8_t e, uint8_t r, uint8_t lo, uint8_t hi);
void sendViewMode(uint8_t mode);
void refreshDisplay();   // Temporización + updateOLED (fuera del loop)
void updateOLED();
void blinkLed();

// ═════════════════════════════════════════════════════════
//  SETUP
// ═════════════════════════════════════════════════════════
void setup() {
  Serial.begin(115200);
  delay(2000);

  pinMode(LED_PIN, OUTPUT);
  digitalWrite(LED_PIN, LOW);

  Serial.println(F(""));
  Serial.println(F("  +----------------------------------+"));
  Serial.println(F("  |  AMR  ·  Feather CAN TX          |"));
  Serial.println(F("  |  Serial->CAN  500 kbps           |"));
  Serial.println(F("  +----------------------------------+"));
  Serial.print(F("  CS Pin: ")); Serial.print(CS_PIN);
  Serial.print(F("   CAN: ")); Serial.print(CAN_BAUDRATE / 1000);
  Serial.println(F(" kbps  [OK]"));
  Serial.println(F(""));
  printMenuInicio();
  printHelp();

  initOLED();
  initCAN();
}

// ═════════════════════════════════════════════════════════
//  LOOP — Ligero: solo funciones (lógica fuera del loop)
// ═════════════════════════════════════════════════════════
void loop() {
  processSerial();
  refreshDisplay();
}

// ═════════════════════════════════════════════════════════
//  Inicialización OLED
// ═════════════════════════════════════════════════════════
void initOLED() {
  Serial.print(F("OLED init... "));
  oledOk = display.begin(SSD1306_SWITCHCAPVCC, SCREEN_ADDRESS);
  if (!oledOk) {
    Serial.println(F("no encontrada"));
    return;
  }
  Serial.println(F("OK"));

  display.clearDisplay();
  display.drawRect(0, 0, SCREEN_WIDTH, SCREEN_HEIGHT, SSD1306_WHITE);
  display.setTextSize(1);
  display.setTextColor(SSD1306_WHITE);
  display.setCursor(4, 4);
  display.println(F("AMR  CAN TX"));
  display.drawFastHLine(0, 14, SCREEN_WIDTH, SSD1306_WHITE);
  display.setCursor(4, 18);
  display.println(F("500 kbps  Serial->CAN"));
  display.setCursor(4, 28);
  display.println(F("B/D/M  1,2=vista RX"));
  display.setCursor(4, 42);
  display.println(F("Listo."));
  display.display();
}

// ═════════════════════════════════════════════════════════
//  Inicialización CAN
// ═════════════════════════════════════════════════════════
void initCAN() {
  Serial.print(F("CAN init (CS="));
  Serial.print(CS_PIN);
  Serial.print(F(", "));
  Serial.print(CAN_BAUDRATE / 1000);
  Serial.println(F(" kbps)..."));
  delay(100);   // Dar tiempo al MCP2515 tras el encendido

  if (!mcp.begin(CAN_BAUDRATE)) {
    Serial.println(F("[ERROR] No se pudo inicializar MCP2515"));
    Serial.println(F("  Revisa: 1) Placa = Adafruit Feather RP2040 CAN"));
    Serial.println(F("  2) Cable/terminal CAN  3) Alimentacion"));
    while (1) {                       // Parpadeo rápido = error
      digitalWrite(LED_PIN, HIGH); delay(100);
      digitalWrite(LED_PIN, LOW);  delay(100);
    }
  }
  Serial.println(F("[OK] MCP2515 inicializado correctamente"));
}

// ═════════════════════════════════════════════════════════
//  Lectura de Serial y envío por CAN
// ═════════════════════════════════════════════════════════
void processSerial() {
  while (Serial.available()) {
    char c = (char)Serial.read();
    if (c == '\n' || c == '\r') {
      if (serialIdx > 0) {
        serialBuf[serialIdx] = '\0';
        parseAndSendCommand(serialBuf);
        serialIdx = 0;
      }
    } else if (serialIdx < SERIAL_BUF_SIZE - 1) {
      serialBuf[serialIdx++] = c;
    }
  }
}

// Avanzar 'line' tras espacios y un número (ej. " 128" o " 50")
static void skipSpacesAndNumber(char*& line) {
  while (*line == ' ' || *line == '\t') line++;
  while (*line >= '0' && *line <= '9') line++;
}
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

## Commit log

2026-03-13 feat: initial professional release - README, CI/CD, PCB, firmware, 3D models
    Made-with: Cursor
    [CajaNuevaAMRF2.STL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]
2026-03-13 fix: Arduino CLI version pinned to 0.35.0 + add PCB EasyEDA workflows
    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
2026-03-13 fix: PCB Preview cache + Arduino CLI config (use --additional-urls flag)
    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
2026-03-13 feat: add PCB + 3D workflows to CI checks (Diseño_CAJA base para PCB)
    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
2026-03-13 docs: add PCB + 3D preview section (viewer embeds, Diseño_CAJA)
    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
2026-03-13 docs: mejoras sección 3D - enlace visor GitHub, script ASCII STL, preview
    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
    [caja_ascii.stl]
2026-03-16 Aesthetic README with 3D PCB placeholders and dark mode dashboard
2026-03-16 Eliminar link de Vercel y regresar a htmlpreview (GitHub)
2026-03-16 fix(3d_viewer): fix scaling and camera target to make PCB visible
2026-03-16 perf: convert 3D PCB to optimized GLB format to load instantly
2026-03-16 feat: enhance 3D materials to look photorealistic like PCBway
2026-03-16 chore: reemplaza SVG placeholder por render real de la PCB
2026-03-16 feat: add AMR1 robot 3D viewer and update README
    - Add docs/amr1_viewer/index.html — self-contained WebGL viewer for AMR1
    - Add AMR1_CAD/amr1.glb — robot assembly 3D model
    - Update README with AMR1 robot 3D viewer section
2026-03-16 fix: remove corrupt DDS images from AMR1 GLB
    SolidWorks embedded 2x DDS textures mislabeled as image/png causing
    "source image could not be decoded" error in Three.js GLTFLoader.
    No materials referenced these textures so removal is safe.
    File size: 6.5 MB -> 3.8 MB.
2026-03-16 fix: rebuild AMR1 viewer and decode GLB without Draco
    Root cause: SolidWorks GLB used KHR_draco_mesh_compression + embedded
    DDS textures mislabeled as PNG. Three.js r128 couldn't handle either.
    Fix:
    - Used gltf-transform to decompress Draco and simplify geometry
    - Stripped corrupt DDS images with Python
    - Rebuilt viewer from working PCB viewer base (correct Three.js inlined)
    - GLB: 6.5MB Draco+DDS -> 6.5MB clean (0 images, 0 textures, 4 meshes)
    - No special extensions required
2026-03-16 docs: improve README with robot specs, fixed badges, updated structure
    - Fix CAD badge: Fusion 360 -> SolidWorks
    - Update subtitle to reflect full platform (robot + PCB + firmware)
    - Add AMR1 robot specs table (chassis, motor, braking, power)
    - Remove empty/commented gallery section
    - Update repo structure to include AMR1_CAD and amr1_viewer
    - Expand system architecture diagram to show full robot topology
    - Reorder sections: Robot viewer -> PCB viewer -> specs -> architecture
2026-03-16 fix(3d_viewer): use jsDelivr CDN for GLB and fix es-module-shims loading
    - Switch GLB URL from raw.githubusercontent.com to cdn.jsdelivr.net/gh
    which is a proper CDN designed for GitHub assets (better CORS, caching,
    and reliability for binary files served to htmlpreview.github.io)
    - Remove async attribute from es-module-shims script to prevent race
    condition where the module script executes before the shim loads
    - Rewrite README to be fully professional: structured specs tables,
    system architecture diagram, clean repo tree, and fabrication guide
2026-03-16 fix(3d_viewer): complete rewrite for reliability and debug visibility
    - Remove importmap + es-module-shims in favor of direct ESM URL imports,
    which are natively supported and work reliably on htmlpreview.github.io
    - Add multi-CDN fallback: tries jsDelivr first, then raw.githubusercontent.com
    - Use fetch() with streaming to show real download progress (MB / total MB)
    - Parse GLB with GLTFLoader.parse() so errors are caught and displayed
    - Show visible error box with the exact error message + retry button
    (previously errors were silent and the spinner ran forever)
    - Add ground plane, grid helper, and improved camera auto-fit after load
    - Improve PCB material heuristics and shadow casting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
2026-03-16 fix(3d_viewer): switch to UMD global scripts to bypass htmlpreview CSP
    htmlpreview.github.io blocks ES module imports (type=module) from external
    CDNs via Content Security Policy, causing the page to freeze silently on
    'Iniciando visor 3D...' indefinitely.
    Fix: load Three.js r128, OrbitControls, and GLTFLoader as plain UMD <script>
    tags (no type=module, no importmap). These are never blocked by CSP and
    work in all browsers and hosting proxies.
    Also adds:
    - XHR-based loading with real byte-level progress bar
    - Multi-CDN fallback (jsDelivr → raw.githubusercontent.com)
    - Visible error box with actionable message if all sources fail
    - Sanity check that THREE and GLTFLoader actually loaded
    C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
2026-03-16 docs(readme): add prominent 3D viewer CTA and improve visual structure
    - Move interactive viewers to top with large clickable badge buttons
    - Add feature comparison table (3D Viewer vs iBOM)
    - Add commented-out image section ready to activate when screenshots
    are added to docs/hardware/images/
    - Make 3D render image clickable to open the interactive viewer
    - Clean up spec tables and system architecture diagram
2026-03-16 fix(viewer)+docs: improve 3D materials, reduce brightness, Spanish README
    Viewer:
    - Reduce ambient light 0.5→0.25, sun 2.0→1.2, point lights 4/2→1.8/0.8
    - Fix FR4 substrate (white) → cream/ivory tint (0xdfd8c8), very matte
    - Add teal/blue solder mask detection (EasyEDA default export color)
    - Add realistic copper pad color (0xb87333) for orange/copper parts
    - Fine-tune all roughness/metalness values per component type
    README:
    - Translate fully to Spanish
    - Add clickable SVG preview image of the PCB that opens the 3D viewer
    - SVG shows isometric PCB illustration with components and specs panel
    - Keep interactive viewer as primary hero section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
2026-04-11 Add CAN BUS base functional code (sender and receiver)
2026-04-11 feat: add OLED timer sketch for Feather RP2040 (standalone, no CAN dependency)
2026-04-16 feat: add AMR1 dashboard decoder and OLED CAN sketches
    - debug_control_AMR1: SBUS decoder with ANSI terminal dashboard for Feather RP2040 CAN, shows throttle/brake/steering/gear/reverse bars and all 16 channels
    - CAN_BUS_OLED: OLED display sketches for CAN bus monitoring
    [can_receiver_oled.ino, can_sender_oled.ino, debug_control_AMR1.ino]
2026-04-16 feat: add SBUS decoder with OLED display (debug_control_AMR1_OLED)
    Combines ANSI serial dashboard with 128x64 SSD1306 OLED showing:
    - VEL/DIR/BRAKE bars with mapped values
    - EN / REV / GEAR status blocks (inverted when active)
    - Raw CH1-4 values on bottom strip
    - Signal lost screen when TX disconnected
    [debug_control_AMR1_OLED.ino]
2026-04-22 Update firmware sketches and project files
    [Battery.SLDPRT, Behälter Deckel.SLDPRT, Blechkasten.SLDPRT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]
